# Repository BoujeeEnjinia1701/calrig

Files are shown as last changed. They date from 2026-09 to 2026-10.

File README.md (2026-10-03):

# CalRig

     

**Area:** Open Engineering · **TRL:** 3 of 9 (analytical proof of concept) · **Value-engineering target:** $412 USD (a hypothetical control target, not a limit) · **Difficulty:** 3 of 5

A calibration rig for low-cost sensors: a sealed chamber with controlled temperature, humidity and particle levels plus reference instruments, so every lab sensor can be checked against a known value before and after deployment.

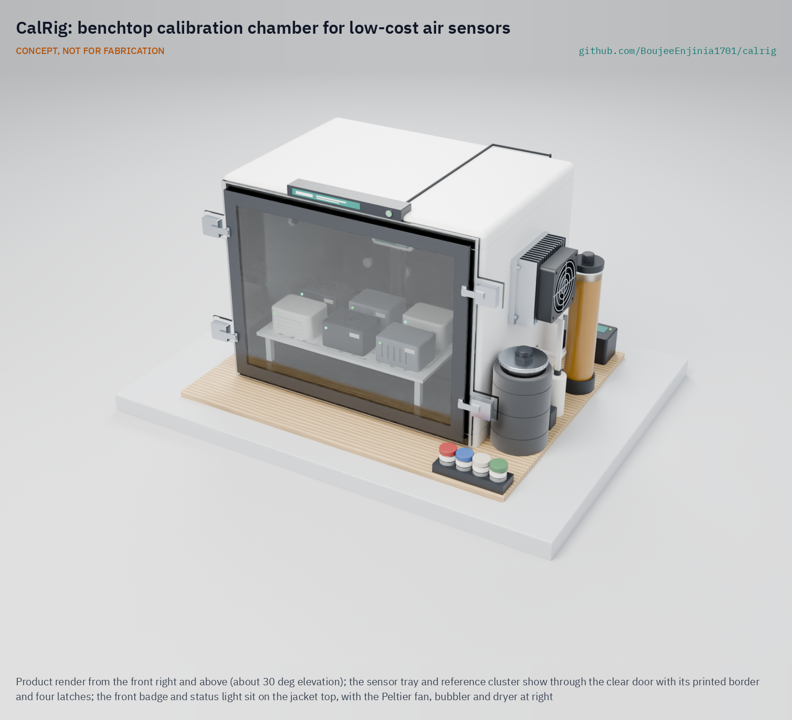
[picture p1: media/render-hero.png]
CalRig: benchtop calibration chamber for low-cost air sensors, product render


[Exploded render](media/render-exploded.png) · [Detail render](media/render-detail.png) · [Interactive 3D model](media/viewer.html) · [Concept blueprint (PDF)](media/concept-blueprint.pdf) · [General arrangement CLR-DWG-001 (PDF)](cad/drawings/CLR-DWG-001.pdf) · [Calculations CLR-CAL-001](docs/04-calcs/01-sizing.md) · [Prototype build plan](docs/05-build-plan.md) · [Review note](docs/REVIEW.md)

## Concept rationale

Calibration is what turns a cheap sensor into a measurement. Most of the error in a low-cost particle, humidity or CO2 sensor comes from temperature, humidity and drift, and those can be set and checked in a small sealed box. CalRig does the chamber half of the recognized method (known conditions, reference instruments, a dated record) and carries a field-collocated reference sensor back to the bench for the particle half, so one shared rig raises the credibility of every sensing project in the lab.

It is open and garage-buildable because the people who most need calibration, community networks and labs in places without regulatory monitors, cannot buy a commercial environmental chamber. Sheet acrylic, a Peltier module, two aquarium-class pumps, silica gel, laboratory salts for humidity fixed points and a microcontroller are available almost everywhere, and an open method lets others check the results.

## Burning platform

Air pollution is a very large health burden, and much of the world measures it with low-cost sensors or not at all. In 2019, 99 % of the world's population lived where WHO air quality guideline levels were not met, and ambient air pollution caused an estimated 4.2 million premature deaths, about 89 % of them in low- and middle-income countries ([WHO fact sheet](https://www.who.int/news-room/fact-sheets/detail/ambient-(outdoor)-air-quality-and-health)). In 2020 OpenAQ found evidence that only 49 % of national governments produced any air quality data ([OpenAQ, 2020](https://documents.openaq.org/reports/Open+Air+Quality+Data+Global+State+of+Play+2020.pdf)).

Low-cost sensors fill that gap only if they are corrected. Raw PurpleAir particle sensors overestimated PM2.5 by about 40 % across most of the United States until a humidity-aware correction cut the error from 8 to 3 µg/m³ ([Barkjohn et al., 2021](https://amt.copernicus.org/articles/14/4617/2021/)), and the UK Air Quality Expert Group warns that without ongoing calibration their useful life "will always be limited" ([DEFRA AQEG](https://uk-air.defra.gov.uk/research/aqeg/pollution-sensors/how-could-I-use.php)).

## Where it could be used

### By industry

| Industry | Use |
| --- | --- |
| Municipal air quality programs | Screen and recheck community PM2.5 sensors before and after each season |
| Universities and schools | Teaching lab for measurement uncertainty; local characterization of sensors for research networks |
| Building services and HVAC | Check CO2 and humidity sensors that drive ventilation control |
| Occupational health | Check the humidity response of wearable particle monitors before field use |
| Agriculture and cold chain | Check temperature and humidity loggers used in grain stores and cold rooms |
| Open hardware and citizen science | Publish a calibration record with every open sensor design |

### By country or region

| Country or region | Why it matters there |
| --- | --- |
| United States | The EPA publishes PM2.5 sensor performance targets and enhanced chamber test conditions ([EPA](https://www.epa.gov/air-sensor-toolbox/frequently-asked-questions-reports-air-sensor-performance-testing-protocols)); CalRig lets community groups report against them without a commercial chamber |
| United Kingdom and European Union | DEFRA's expert group calls for ongoing calibration of sensors ([DEFRA AQEG](https://uk-air.defra.gov.uk/research/aqeg/pollution-sensors/how-could-I-use.php)), and CEN/TS 17660-1 tests sensor systems across temperature and humidity ([CEN/TS 17660-1:2021](https://standards.iteh.ai/catalog/standards/cen/5bdb236e-95a3-4b5b-ba7f-62ab08cd21f8/cen-ts-17660-1-2021)) |
| Uganda and Kenya | Listed by OpenAQ in 2020 among populous countries with no national government air quality monitoring program ([OpenAQ, 2020](https://documents.openaq.org/reports/Open+Air+Quality+Data+Global+State+of+Play+2020.pdf)); local groups already calibrate low-cost sensor networks ([Uganda study](https://www.sciencedirect.com/science/article/pii/S1309104225001825)) |
| Nigeria and West Africa | Nigeria, with about 206 million people, was also on OpenAQ's 2020 list of countries without a national monitoring program ([OpenAQ, 2020](https://documents.openaq.org/reports/Open+Air+Quality+Data+Global+State+of+Play+2020.pdf)); low-cost networks there need local checks in heat and high humidity |
| South and Southeast Asia | WHO reports the greatest burden of ambient air pollution deaths in its South-East Asia and Western Pacific regions ([WHO](https://www.who.int/news-room/fact-sheets/detail/ambient-(outdoor)-air-quality-and-health)); dense sensor networks in humid climates depend on humidity correction |

## What sparked the idea

The idea traces back to the 2020 wildfire season in the western United States. From August to December 2020, the US EPA and the US Forest Service ran the AirNow Sensor Data Pilot, which put readings from a commercial network of PurpleAir sensors on the public Fire and Smoke Map. Before they could do that, EPA researchers had to deal with the fact that the sensors consistently overestimated PM2.5, so they developed a correction equation and quality control checks and validated them for smoke ([EPA, 2021](https://www.epa.gov/sciencematters/research-supports-air-sensor-data-pilot-conducted-2020-wildfire-season)). The lesson is that thousands of low-cost sensors became useful to the public only once someone characterized them against reference instruments in smoke and humid air. CalRig applies the same step at bench scale, so that a small network can check its sensors in known smoke and humidity before its data are published.

## Problem

Low-cost sensors drift and disagree, and without calibration their data is not trusted by cities, regulators or researchers. Full problem statement: [docs/01-problem.md](docs/01-problem.md).

## Concept

A bench-top, 36 L insulated acrylic chamber sets known temperature (10 to 40 °C in rooms up to 25 °C), humidity (20 to 85 % RH) and particle levels (clean air, then a controlled smoke decay from about 300 µg/m³) around up to six sensors. Reference sensors, checked against salt humidity fixed points, an ice point and a 30-day field collocation for the particle reference, give the known values. Larger sensor heads take two or four of the six bays. A controller steps through set points and a laptop script writes a calibration record for each sensor, reported against the US EPA PM2.5 sensor targets.

Calculated performance (TRL 3, [CLR-CAL-001](docs/04-calcs/01-sizing.md)): a four-point sweep plus a particle run takes about 5.5 h unattended; about 90 W peak from an external 12 V supply; 600 x 500 x 383 mm and about 13.9 kg. A larger inner Peltier sink keeps the 85 % RH point at 20 °C dry in rooms up to about 28 °C. Twelve of eighteen requirements are met on paper. Not met: particle traceability until the transfer sensor has been collocated (a first candidate site is named). Value-engineering target: USD 412. Estimated cost of the constructable design: USD 448.50 (USD 36.50 over the target). Each sensor gets a one-page report to the US EPA 2021 targets for PM2.5 sensors. NO2 is calibrated by field collocation, not on CalRig.

Full design precis: [docs/02-concept.md](docs/02-concept.md). Requirements: [docs/03-requirements.md](docs/03-requirements.md).

## Key components

1. Sealed 6 mm acrylic chamber (36 L) with front door and removable insulation jacket
2. 60 W Peltier heat pump with an enlarged inner fin block, and an internal mixing fan
3. Heated bubbler (wet air) and silica gel dryer (dry air), mixed by two pumps
4. HEPA scrubber loop and aerosol injection port for zero air and smoke decay
5. Reference cluster: two Sensirion SHT45, a Sensirion SCD30 (CO2) and a collocated Sensirion SPS30 (PM)
6. Six-bay sensor tray, controller with independent thermal cut-off, certified external 12 V supply
7. Saturated salt fixed-point jars for checking the humidity references

The working bill of materials is in [bom/bom.csv](bom/bom.csv).

## Building the prototype

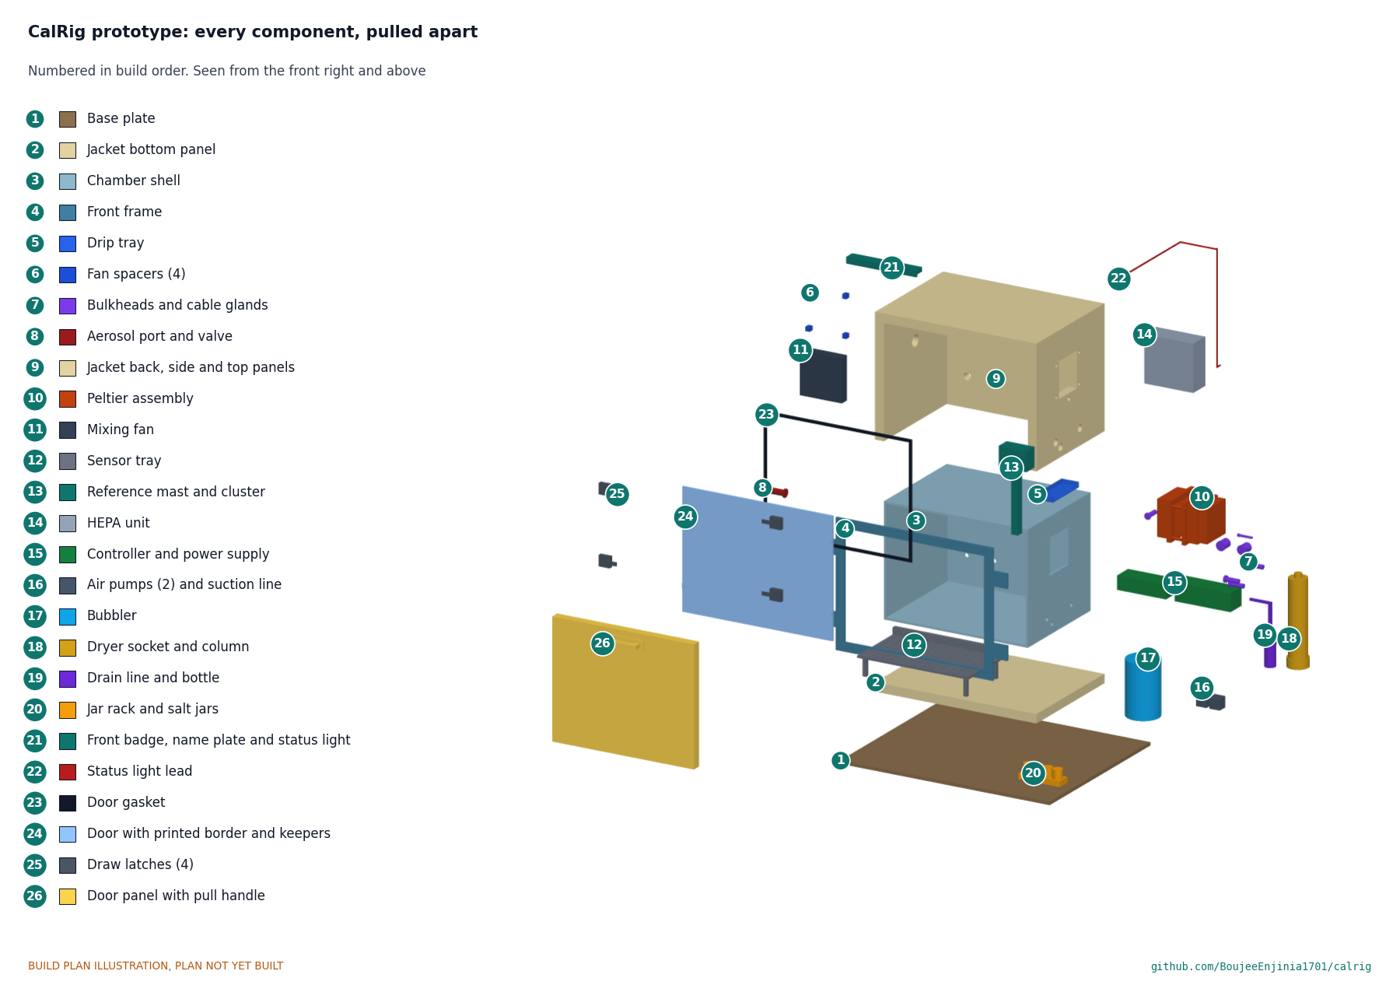
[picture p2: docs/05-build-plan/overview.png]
CalRig prototype: every component pulled apart and numbered in build order


The [prototype build plan](docs/05-build-plan.md) (CLR-BLD-001) shows, in pictures, how to make each of the 26 components and put them together in fourteen steps; nothing has been built yet. The made parts are a laser-cut acrylic chamber with a welded front frame, drip tray and fan spacers, a perforated sensor tray, a clear door, five foam jacket panels and a foam door panel, a sealed plywood base, three printed holders, a front badge with the name plate and a status light, and a pull handle for the door panel; everything else is bought and fitted. Writing the plan made the design buildable: the door now seals on a welded frame with four latches, the heat pump clamps the wall, the air loops, HEPA unit and leads pass through bulkhead fittings and glands, and a drip tray drains to a bottle (CLR-DDR-003, accepted by Amish on 2026-10-02). Every picture is drawn from the model, and the model checks that each part touches what it should and clears what it should not.

## Safety

> **Safety:** No mains wiring inside the rig; use only a certified external 12 V supply. The Peltier hot side reaches 60 to 70 °C and is guarded, with an independent thermal cut-off. Test smoke contains fine particles and some carbon monoxide: light it outside the chamber in a ventilated room and clear the chamber through the HEPA loop before opening. Soda lime is corrosive and lithium chloride is harmful if swallowed; wear gloves and eye protection. No toxic calibration gases are used.

## Repository layout

| Folder | Contents |
| --- | --- |
| `docs/` | Problem, concept, requirements, calculations and design decisions |
| `cad/src/` | build123d Python source, the source of truth for all geometry |
| `cad/step/`, `cad/stl/` | Exported models for FreeCAD, other CAD tools and printing |
| `cad/drawings/` | 2D sketches and dimensioned drawings |
| `bom/` | Bill of materials |
| `electronics/` | KiCad schematics and PCB layouts |
| `firmware/` | Microcontroller code |
| `media/` | Renders, perspectives and photos |
| `build-log/` | Dated prototyping notes |

## Documentation

Controlled documents follow the portfolio [documentation standard](.kit/STANDARDS.md). Each carries a document ID (CLR-PRC-001 for the precis), a version and a revision history. Branded PDFs are built with `python .kit/render.py` and attached to GitHub Releases when a document is tagged, for example `CLR-PRC-001/v1.0`.

## Credits

Designed by Amish Chadha. See [CONTRIBUTORS.md](CONTRIBUTORS.md) for roles. To cite this design, use [CITATION.cff](CITATION.cff) (GitHub shows it as "Cite this repository").

AI assistance (Claude) was used to accelerate concept renders, prototype documentation and first-pass sizing calculations. Design direction and all decisions are Amish Chadha's, recorded in this repository's decision records (`docs/decisions/`).

## Licenses

- **Hardware** (CAD, drawings, BOM, electronics): [CERN-OHL-S v2](LICENSE)
- **Software** (firmware, scripts, notebooks): [MIT](LICENSE-SOFTWARE)

A project of the [Design Molecule](https://designmolecule.com) lab.

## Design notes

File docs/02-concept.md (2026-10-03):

---
doc_id: CLR-PRC-001
title: CalRig design precis
project: CalRig
doc_type: Design precis
version: "0.9"
status: Draft
date: '2026-10-02'
author: Amish Chadha
license: CERN-OHL-S-2.0
revisions:
- version: "0.1"
  date: '2026-09-25'
  author: Amish Chadha
  change: Initial scaffold
- version: "0.3"
  date: '2026-09-25'
  author: Amish Chadha
  change: Populate to TRL 2 (how it works, components, first-order numbers, safety, open questions)
- version: "0.3"
  date: '2026-09-25'
  author: Amish Chadha
  change: TRL 2 review items adopted for TRL 3 work (CLR-DDR-001); numbers replaced by CLR-CAL-001 results; full jacket, 120 mm fan, sleeved bubbler with trace-heated line, 600 x 500 mm base
- version: "0.4"
  date: '2026-09-25'
  author: Amish Chadha
  change: Recommendations accepted by Amish (DDR-002). Larger inner Peltier sink, budget $400, mass limit 14 kg; numbers from CLR-CAL-001 v0.2
- version: "0.5"
  date: '2026-09-26'
  author: Amish Chadha
  change: Budget approved by Amish; $412 budget covers the priced BOM
- version: "0.6"
  date: '2026-10-01'
  author: Amish Chadha
  change: "Constructable design (CLR-DDR-003): front frame, four latches, back-wall glands and bulkheads, drain, 9 mm base; numbers from CLR-CAL-001 v0.4"
- version: "0.7"
  date: '2026-10-01'
  author: Amish Chadha
  change: Budget treated as a value-engineering target; cost wording only, no number changed
- version: "0.8"
  date: '2026-10-02'
  author: Amish Chadha
  change: 'Decisions of 2026-10-02: collocation site first candidate, report format, large heads in two or four bays'
- version: "0.9"
  date: '2026-10-02'
  author: Amish Chadha
  change: 'Approved follow-ups carried out: front badge with name plate and status light, printed door border and pull handle in the design (component 20); per-sensor report template (R14); large heads checked in the model; numbers from CLR-CAL-001 v0.7 (13.9 kg, 383 mm, $448.50)'
---

# CalRig design precis

## Summary

CalRig is a 36 L insulated acrylic chamber on a bench-top base. A Peltier heat pump sets the temperature, a heated bubbler and a silica gel dryer set the humidity, a HEPA loop gives clean air and a controlled smoke decay for particle tests, and a reference cluster (two Sensirion SHT45 temperature and humidity sensors, a Sensirion SCD30 CO2 sensor and a collocated Sensirion SPS30 particle sensor) sits among six sensors under test. A small controller steps through set points, logs everything and shows its state on a status light on the front badge; a laptop script fits a correction for each sensor and writes a dated report to the US EPA 2021 targets (see Per-sensor calibration report). The calculations in CLR-CAL-001 v0.7 show that it meets twelve of the eighteen requirements in CLR-REQ-001. Making the design buildable (CLR-DDR-003, accepted by Amish on 2026-10-02) added a front frame, bulkhead fittings, cable glands, a drain and printed holders, and the details adopted on 2026-10-02 added the front badge, a printed door border and a pull handle. Value-engineering target: USD 412. Estimated cost of the constructable design: USD 448.50 (USD 36.50 over the target; see the value engineering section of CLR-DEC-001). How to build the prototype is in the build plan, CLR-BLD-001. Its particle reference depends on a collocation site; the first candidate is named in CLR-DEC-001.

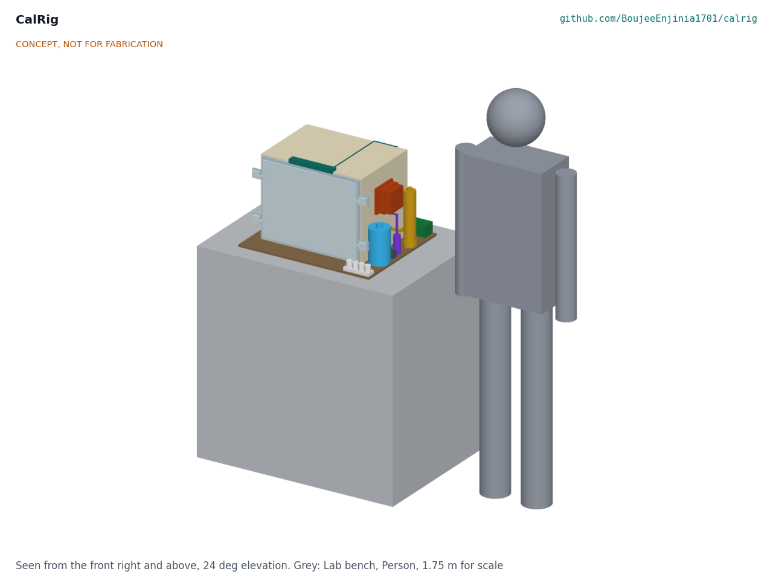
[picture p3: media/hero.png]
Figure 1. CalRig massing model on a lab bench with a 1.75 m person for scale.


Figure 1. CalRig massing model on a lab bench, with a 1.75 m person for scale. Concept, not for fabrication.

## How it works

1. **Load.** Up to six sensor heads sit in the bays of a tray inside the chamber. Their leads pass through two sealed glands in the back wall to a USB and I2C hub on the controller. The door is closed and latched.
2. **Check the references.** Before a campaign (monthly is proposed), the two SHT45 references are checked at four saturated salt fixed points (11, 33, 75 and 84 % RH at 25 °C; [Greenspan, 1977](https://nvlpubs.nist.gov/nistpubs/jres/81A/jresv81An1p89_A1b.pdf)) and in an ice bath at 0 °C. The SPS30 transfer sensor is collocated at a regulatory or research monitor for 30 days or more, and replaced in the chamber only if it meets the US EPA PM2.5 targets there.
3. **Temperature and humidity sweep.** The controller steps through set points, by default 20 °C and 40 °C at 40 % and 85 % RH, matching the EPA enhanced test conditions ([EPA FAQ](https://www.epa.gov/air-sensor-toolbox/frequently-asked-questions-reports-air-sensor-performance-testing-protocols)). The sweep runs from cold to hot, because cooling is the slow direction. The Peltier assembly heats or cools. Two small pumps draw air from the chamber and return it through the bubbler (wet) and the dryer (dry) at a ratio set by PWM, with about 3 L/min in total. The internal 120 mm fan mixes the chamber. Each point settles in about 22 to 31 min, then allows 15 min for the heads to equilibrate, and is held for 30 min (CLR-CAL-001, section I).
4. **Particle run.** With the HEPA loop at full speed (about 20 L/min) the chamber is cleaned to below 2 µg/m³ in about 5 min. A syringe draws a puff of smoke from an incense stick smoldering in a cup outside the chamber and injects it through the aerosol port. The HEPA loop then runs slowly (5 L/min) and the concentration decays from about 300 to 5 µg/m³ in about 28 min, giving a continuous comparison curve. The run can be repeated at a second humidity to fit the humidity term.
5. **CO2 check (optional).** Soda lime in the dryer path gives a near-zero point. One liter of exhaled breath from a bag raises the chamber by about 1,100 ppm for a span point.
6. **Fit and record.** The laptop script compares each sensor with the references, fits a slope, offset and humidity term, computes the EPA metrics (R², slope, intercept, RMSE, sensor-to-sensor precision) and writes a CSV and a one-page report per sensor serial number, laid out as in the per-sensor calibration report below. The status light on the front badge shows whether a run is in progress, settled or finished.

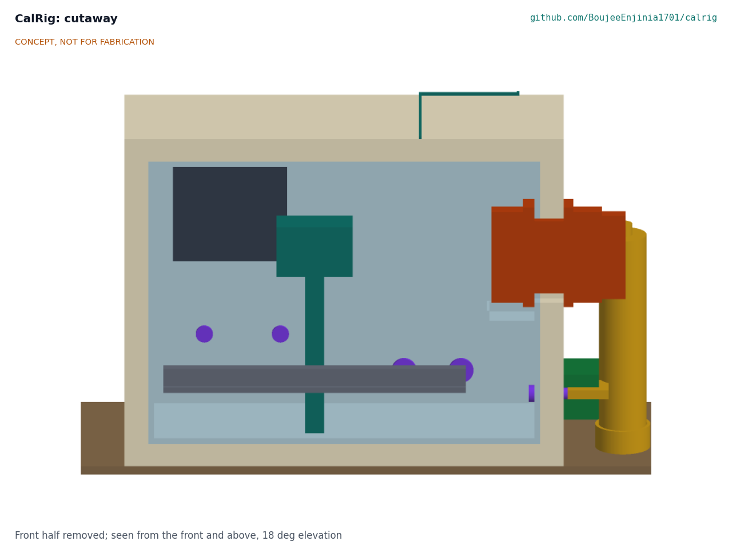
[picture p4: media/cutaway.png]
Figure 2. Cutaway: sensor tray, reference cluster, mixing fan and Peltier assembly.


Figure 2. Cutaway looking from the door side: sensor tray with six example sensors, reference cluster on its mast, mixing fan and the Peltier assembly through the right-hand wall.

## Main components

Table 1. Main components, numbered to match the BOM and the exploded view (Figure 3).

| No. | Component | Role | Key choice |
| --- | --- | --- | --- |
| 1 | Chamber shell | 36 L sealed volume (400 x 300 x 300 mm inside) | 6 mm cast acrylic, solvent-welded; small enough to condition fast, large enough for six heads |
| 2 | Front door | Access and viewing | 430 x 330 mm clear acrylic door with a 22 mm printed black border, on a front frame welded to the shell, silicone gasket, four draw latches; no gland in the door |
| 3 | Insulation jacket | Cuts the chamber conductance to about 0.82 W/K | 25 mm XPS on every face except the door, plus a removable door panel with a printed pull handle for hot, humid and cold points |
| 4 | Base plate | Carries the chamber and conditioners | 9 mm sealed birch plywood, 600 x 500 mm, six rubber feet |
| 5 | Peltier heat pump | Heats and cools the chamber | 60 W air-to-air thermoelectric assembly; the stock inner sink is replaced by a larger fin block (about 45 x 120 x 110 mm, about 0.20 K/W with its fan) so it stays above the dew point at 20 °C and 85 % RH (CLR-DDR-002) |
| 6 | Internal mixing fan | Uniform air across the bays | 120 mm, 12 V, speed-controlled (80 mm was too small for R4) |
| 7 | Sensor tray | Holds six sensor heads, cable rail | Perforated sheet so air moves around the heads |
| 8 | Reference cluster | The known values | 2 x SHT45 (±0.1 °C, ±1.0 % RH typical, [Sensirion](https://sensirion.com/products/catalog/SHT45)), SCD30 (±(30 ppm + 3 %), [Sensirion](https://sensirion.com/products/catalog/SCD30)), SPS30 collocated transfer sensor (±10 % precision, [Sensirion](https://sensirion.com/products/catalog/SPS30)) |
| 9 | Humidifier bubbler | Wet air | 0.3 L of distilled water in a foam-sleeved jar with a 10 W heater pad, held about 3 K above chamber air; trace-heated outlet line so the wet air does not condense on the way; no ultrasonic mist, which would add particles |
| 10 | Dryer column | Dry air | Indicating silica gel, about 500 g, regenerated in an oven |
| 11 | HEPA scrubber loop | Zero air and controlled smoke decay | H13 class filter cartridge with a variable-speed fan, joined to the chamber by two bulkheads in the back wall |
| 12 | Aerosol injection port | Smoke entry | Luer port with a ball valve; the smoke source stays outside |
| 13 | Controller and power board | Control, logging and protection | ESP32 class board, Peltier H-bridge, pump and fan MOSFETs, a status light output, microSD, independent thermal cut-off |
| 14 | Power supply | 12 V, 10 A | Certified external brick; no mains wiring in the rig |
| 15 | Salt fixed-point jars | Humidity reference checks | LiCl, MgCl2, NaCl and KCl slurries in sealed jars |
| 19 | Bulkhead fittings, glands and drain | Air, water and leads through the sealed walls | Five 12 mm bulkheads, a 6 mm drain, two M20 cable glands in the back wall, 250 mL drain bottle |
| 20 | Front badge, status light and name plate | Shows run state without opening the rig | Printed badge on the jacket's top panel with a 12 V panel light and the name plate; lead to the controller |

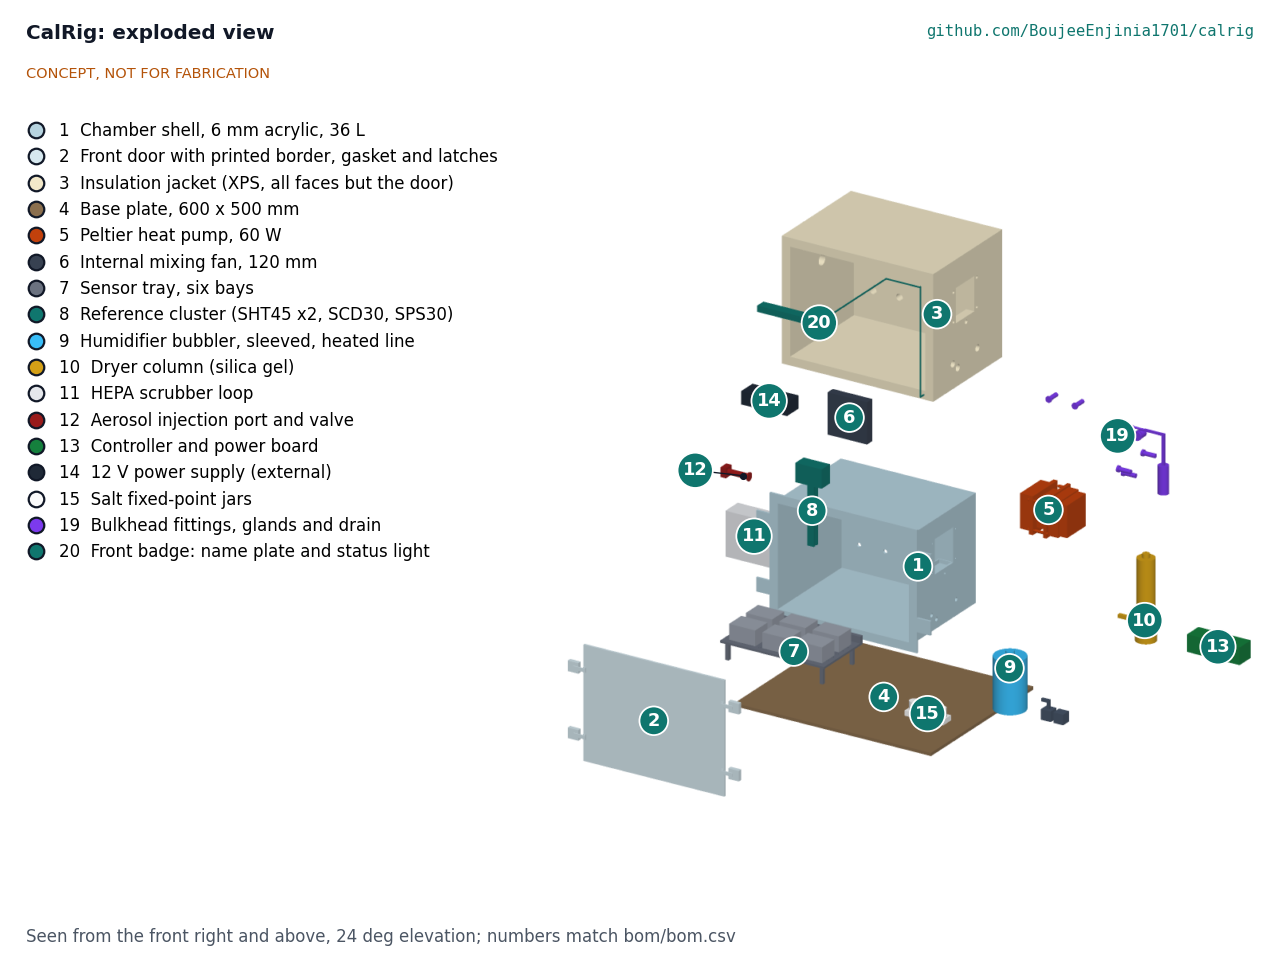
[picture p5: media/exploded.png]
Figure 3. Exploded view with BOM numbers.


Figure 3. Exploded view. Callout numbers match Table 1 and `bom/bom.csv`.

## Key numbers

All values come from CLR-CAL-001 v0.7, which gives the assumptions and the script tags. They are calculations, not measurements.

Table 2. Chamber and process figures.

| Quantity | Value | Basis |
| --- | --- | --- |
| Internal volume | 36.0 L | 400 x 300 x 300 mm |
| Chamber conductance | 0.82 W/K with door panel; 1.17 W/K without | Full jacket (U 1.01 W/(m²·K)), 20 % for thermal bridges, conditioning loop 0.06 W/K |
| Internal heat gains | 6.7 W | Fans 3.9 W, six heads 2.4 W, references 0.4 W |
| Water to go from 20 to 85 % RH at 40 °C | 1.8 g | 1.19 g in the air, about 0.59 g into the acrylic surface |
| Settling per set point | 22 to 31 min, plus 15 min for the heads | Loop time constant 12 min; full-drive thermal ramps |
| Four-point sweep plus particle run | about 5.5 h | Cold to hot, 30 min holds |
| Decay 300 to 5 µg/m³ | about 28 min | HEPA 5 L/min, deposition 0.2 per hour |
| CO2 span from 1 L of breath | about +1,100 ppm | Exhaled air about 4 % CO2 |
| Peak electrical power | about 90 W, 7.5 A at 12 V | Peltier 59 W, heaters 13 W, pumps, fans, controller, sensors |
| Overall size and mass | 600 x 500 x 383 mm; about 13.9 kg | Parametric model `cad/src/model.py` (the front badge sets the height) |
| Capacity | Six heads up to 90 x 70 x 50 mm; or larger heads up to 192 x 70 mm on two bays or 192 x 152 mm on four, up to 234 mm tall | Model checks, CLR-CAL-001 [A2, A4] |

Table 3. Temperature range with one 12706-class module at 12 V (CLR-CAL-001, section B).

| Room | Lowest chamber temperature | Heating to 40 °C |
| --- | --- | --- |
| 15 °C | -2.0 °C | 13.9 W needed, about 80 W available |
| 22 °C | 4.1 °C | 8.1 W needed, about 86 W available |
| 25 °C | 6.7 °C | Met |
| 30 °C | 11.1 °C | Met |

The revised R1 (10 °C in rooms of 15 to 25 °C) is met, with a 3.3 K margin at 25 °C. Cooling to 10 °C is slow, about 2.5 h in a 25 °C room, so cold points are a separate run.

**Condensation at the hot, humid point.** At 40 °C and 85 % RH the dew point is 37.0 °C. The inner face of the clear door in a 22 °C room runs at about 33 °C and condenses; with the door panel fitted it runs at about 38.2 °C, a 1.2 K margin (0.5 K in a 15 °C room). The door panel is therefore required for that point, and the wet air line is trace-heated.

**Condensation on the Peltier sink.** Holding 20 °C in the 22 °C reference room still needs about 8 W of cooling, mostly to remove the internal gains. With the stock inner sink (0.45 K/W) the sink ran about 1.2 K below the 17.4 °C dew point of air at 85 % RH and would condense about 8 g/h against about 0.7 g/h from the bubbler. The larger inner fin block (about 0.20 K/W, CLR-DDR-002) runs at about 18.3 °C, 0.9 K above the dew point, so the point holds in rooms up to about 28 °C (R2 met). A drip tray and drain stay in the design for cold points.

**Particle reference.** The chamber cannot create a traceable mass reference. It carries one from the field: a transfer SPS30 that has been collocated with a regulatory or research monitor. Chamber results then describe how each sensor compares with that transfer sensor in combustion smoke at known humidity. Reports must state the aerosol type, because optical sensors respond differently to dust, salt and smoke.

## Key design choices

These were decided by Amish on 2026-09-25 (go with recommendation; CLR-DDR-001 and CLR-DDR-002).

- **Transfer references instead of certified instruments.** Certified reference instruments cost thousands of dollars. CalRig uses good digital sensors, checked against physical fixed points (salts, ice) and field collocation. This keeps the rig near its value-engineering target and makes the uncertainty chain explicit.
- **Heated bubbler, not an ultrasonic mister.** Ultrasonic misters make mineral particles that would corrupt particle tests.
- **Smoke decay, not a nebulizer.** A decay curve covers the whole range in one run with no dilution hardware. Every report states the aerosol type (CLR-DDR-001 A4).
- **Accept the cooling limit.** One Peltier module; 10 °C only in rooms at 25 °C or below, and the lowest point stated in each record for warmer rooms (CLR-DDR-001 A3).
- **Insulated door panel** for hot, humid and cold points (CLR-DDR-001 A6).
- **Larger inner Peltier sink** (about 0.20 K/W) so the 20 °C, 85 % RH point holds in normal rooms (CLR-DDR-002).
- **Mass limit of 14 kg.** CalRig is a bench rig, so the 12 kg limit was relaxed rather than thinning the acrylic (CLR-DDR-002).
- **Certified temperature probe if the cost target allows.** It does not yet (the BOM is already above the $412 value-engineering target), so R5 stays at risk (CLR-DDR-002).
- **External 12 V supply.** Keeps mains voltage out of a box that holds water.
- **Temperature and humidity first, CO2 optional, no toxic gases.** NO2 sensors, including AirStreet's, are calibrated by field collocation only (CLR-DDR-001 A5).

## Links to other projects

- **AirStreet** describes itself as "calibrated on CalRig" for PM2.5 and NO2. CalRig covers PM2.5 and the temperature and humidity terms; AirStreet's README already states that NO2 is calibrated by field collocation.
- **HeatMap Node** (heat and humidity), **DustBadge** (dust) and **FieldNode** sensor heads are intended users. Larger heads take more than one bay: a head up to 192 x 70 mm in plan takes two bays side by side, and one up to 192 x 152 mm, such as HeatMap Node's 150 mm globe, a 2 x 2 block of four bays (R10). DustBadge measures respirable dust, so a smoke-based chamber result will not transfer directly to mineral dust.

## Per-sensor calibration report (R14)

Each sensor head gets a one-page report, keyed by its serial number, written from the run's CSV. The report follows the US EPA 2021 performance targets and testing protocol for PM2.5 air sensors (EPA/600/R-20/280, [EPA](https://www.epa.gov/air-sensor-toolbox/air-sensor-performance-targets-and-testing-protocols)), and states its uncertainty chain back to the salt and ice fixed points and the collocation record. It is a research and calibration record for a low-cost sensor, not a certificate of conformity: chamber results compare each sensor with a transfer reference in incense smoke, and the EPA targets are set for 24 h field averages against a regulatory monitor, so the chamber comparison is indicative and says so.

Table 4. Per-sensor report template.

| Section | Contents |
| --- | --- |
| 1. Identification | Sensor make, model, serial number and firmware; CalRig serial and software version; run date, operator; bay position, or the two- or four-bay position for a large head |
| 2. Run conditions | Set points as run (20 °C and 40 °C at 40 % and 85 % RH by default), room temperature, the lowest set point reachable in that room (R1), averaging interval, hold length, number of points; aerosol type (incense smoke) and decay range |
| 3. Reference status | SHT45 serials, date of the last ice-point and salt fixed-point checks and their offsets; transfer SPS30 serial, collocation site, dates (30 days or more), and its collocation results (R², slope, intercept, RMSE) against the regulatory monitor; SCD30 if used, with its datasheet tolerance (no traceable CO2 reference) |
| 4. Fitted correction | Slope, offset and humidity term for PM2.5, with their standard errors; offset and slope for temperature and RH where the sensor reports them |
| 5. EPA metrics, raw and corrected | Slope (target 1.0 ± 0.35), intercept (-5 to +5 µg/m³), R² (0.70 or more), RMSE (7 µg/m³ or less) or NRMSE (30 % or less), and, where three or more of the same model ran together, precision as standard deviation (5 µg/m³ or less) or coefficient of variation (30 % or less); each shown against its target |
| 6. Enhanced conditions | Response at each temperature and humidity set point; humidity influence; drift since the last report for this serial, if there is one |
| 7. Uncertainty chain | Temperature: ice point, SHT45 after offset, drift, gradient to the bay, expanded U (k = 2) from CLR-CAL-001 [F1]. Humidity: salt fixed points (Greenspan, 1977), jar gradient, hysteresis, interpolation and temperature terms, expanded U (k = 2) [F3]. Particles: regulatory monitor at the collocation site, transfer SPS30 collocation results, chamber bay-to-reference gradient, fit residuals; expanded U (k = 2) of the corrected PM2.5 at 35 µg/m³ |
| 8. Limits of use | Aerosol type, ranges covered, the date after which the reference checks lapse, and the statement that the results describe this sensor against the transfer reference in smoke at known humidity |

Values and their units come from the run's CSV and from CLR-CAL-001; the report writer is part of the control and fitting software (BOM line 18), written at TRL 4.

## Safety

> **Safety:** The Peltier hot-side heat sink can reach 60 to 70 °C; keep it guarded and away from the acrylic. An independent thermal cut-off opens the heater circuit at 50 °C chamber air or 70 °C hot side. The 12 V bus carries up to about 7.5 A: fuse it at 10 A at the supply and use rated wire. The bubbler heater pad and the line trace each have a thermistor and are switched off by the same cut-off. Use only a certified external supply; never wire mains into the rig, which contains water.

> **Safety:** Test smoke contains fine particles and combustion gases, including carbon monoxide in small amounts. Light the incense in a cup outside the chamber, in a ventilated room, and run the HEPA loop until the reference reads below 5 µg/m³ before opening the door. No toxic calibration gases are used in this version.

> **Safety:** Soda lime is corrosive and lithium chloride is harmful if swallowed. Wear gloves and eye protection when filling cartridges and salt jars, label them, and keep them away from children. Cast acrylic is combustible: keep heaters and hot surfaces off the shell. Keep electronics below and outside the chamber so condensation cannot reach them. Fans have guards. Exhaled air for CO2 checks goes through a single-user bag and filter.

## Open questions

- [x] Value-engineering target: USD 412 in parts, a hypothetical control target set by Amish on 2026-09-26 (CLR-DDR-002). Estimated cost of the constructable design: USD 448.50 (USD 36.50 over the target); savings worth trying are in the value engineering section of CLR-DEC-001.
- [x] Particle reference: a state or local regulatory monitoring site with a federal equivalent PM2.5 monitor (decided 2026-10-02, CLR-DEC-001). First candidate to approach: a Texas Commission on Environmental Quality site in Dallas-Fort Worth; fallback: South Coast AQMD's AQ-SPEC program. How often the transfer SPS30 returns there is still to be set.
- [ ] Inner fin block: confirm a part that reaches about 0.20 K/W with the inner fan.
- [x] Report format: based on the US EPA 2021 performance targets and testing protocol for PM2.5 air sensors, with a stated uncertainty chain from the salt and ice fixed points and the collocation record (decided 2026-10-02, CLR-DEC-001); template in Table 4.

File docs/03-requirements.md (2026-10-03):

---
doc_id: CLR-REQ-001
title: CalRig requirements
project: CalRig
doc_type: Requirements
version: "0.9"
status: Draft
date: '2026-10-02'
author: Amish Chadha
license: CERN-OHL-S-2.0
revisions:
- version: "0.1"
  date: '2026-09-25'
  author: Amish Chadha
  change: Initial scaffold
- version: "0.3"
  date: '2026-09-25'
  author: Amish Chadha
  change: First measurable requirements for TRL 2, with first-order status
- version: "0.3"
  date: '2026-09-25'
  author: Amish Chadha
  change: R1 redefined per CLR-DDR-001 A3; status column replaced by the CLR-CAL-001 results; budget note per A1
- version: "0.4"
  date: '2026-09-25'
  author: Amish Chadha
  change: Recommendations accepted by Amish (DDR-002). R12 target $400, R13 mass relaxed to 14 kg, statuses from CLR-CAL-001 v0.2
- version: "0.5"
  date: '2026-09-26'
  author: Amish Chadha
  change: Budget approved by Amish; R12 target $412, status Not met to Met
- version: "0.6"
  date: '2026-10-01'
  author: Amish Chadha
  change: Statuses from CLR-CAL-001 v0.4 for the constructable design (CLR-DDR-003); R12 Met to Not met ($439), budget rise proposed; R13 figures updated
- version: "0.7"
  date: '2026-10-01'
  author: Amish Chadha
  change: Budget treated as a value-engineering target; cost wording only, no number changed
- version: "0.8"
  date: '2026-10-02'
  author: Amish Chadha
  change: 'Decisions of 2026-10-02 (CLR-DEC-001): R8 first candidate collocation site named; R10 large item case added; R14 report based on the US EPA 2021 targets and protocol with an uncertainty chain. No status changed'
- version: "0.9"
  date: '2026-10-02'
  author: Amish Chadha
  change: 'Statuses from CLR-CAL-001 v0.7: R10 met including the large item case (was met for six heads only); R12 over the value-engineering target by USD 36.50 (was USD 27); R13 figures 383 mm and 13.9 kg, still met; R14 report template defined, still not verifiable at TRL 3'
---

# CalRig requirements

These requirements have been checked by calculation in CLR-CAL-001 v0.7. Targets are not yet validated with users. R1 was redefined under CLR-DDR-001 (item A3); R12 and R13 were restated under CLR-DDR-002. All three changes were decided by Amish on 2026-09-25 (go with recommendation). Test conditions follow the enhanced lab conditions in the US EPA sensor testing reports (20 °C and 40 °C; 40 % and 85 % RH) so that CalRig results can be read against a known method ([EPA FAQ](https://www.epa.gov/air-sensor-toolbox/frequently-asked-questions-reports-air-sensor-performance-testing-protocols)).

The **reference room** is an indoor lab at 22 °C and 50 % RH unless a requirement states otherwise.

Table 1. Requirements with targets and status from CLR-CAL-001 (Table 4 there gives the values and script tags).

| ID | Requirement | Target | Verification (TRL 3 or later) | Status (CLR-CAL-001) |
| --- | --- | --- | --- | --- |
| R1 | Chamber temperature range | 10 to 40 °C at the sensor tray in a room at 15 to 25 °C; in rooms from 25 to 30 °C, the lowest reachable set point is stated in each calibration record | Heat balance with a thermoelectric model; later chamber log | Met: 6.7 °C reachable in a 25 °C room; 11.1 °C lowest in a 30 °C room |
| R2 | Chamber humidity range | 20 to 85 % RH at any temperature from 20 to 40 °C | Moisture balance; later chamber log | Met: all corners reached in 26 min or less; with the larger inner sink (DDR-002) 20 °C and 85 % RH holds in rooms up to about 28 °C, with a 0.9 K dew point margin in the reference room |
| R3 | Stability at a set point | ±0.3 °C and ±2 % RH over a 30 min hold | Controller simulation; later log | Met on an idealized model: ±0.02 °C, ±1.0 % RH |
| R4 | Uniformity across the six bays | ±0.3 °C and ±2 % RH between bays | Airflow estimate; later traverse with two references | At risk: ±0.18 °C at the EPA points with the 120 mm fan, ±0.42 °C at 10 °C; ±0.8 % RH |
| R5 | Reference temperature uncertainty | 0.2 °C or better (expanded, k = 2) from 10 to 40 °C | Uncertainty budget; ice-point check | At risk: 0.14 °C with the typical sensor tolerance, 0.24 °C if it is 0.2 °C; no calibration certificate |
| R6 | Reference humidity uncertainty | 2 % RH or better (expanded) from 20 to 85 % RH, checked at four salt fixed points | Uncertainty budget; salt fixed-point checks ([Greenspan, 1977](https://nvlpubs.nist.gov/nistpubs/jres/81A/jresv81An1p89_A1b.pdf)) | At risk: 2.0 % RH, no margin |
| R7 | Particle test range | Zero below 2 µg/m³ PM2.5; controlled decay from 300 to 5 µg/m³ in 45 min or less | Decay calculation; later run | Met: 5 min clean-down; 28 min decay |
| R8 | Particle reference traceability | Transfer PM sensor collocated with a regulatory or research monitor for 30 days or more, and meeting EPA PM2.5 targets there, before use as the chamber reference | Collocation record | **Not met by the rig alone.** First candidate site chosen on 2026-10-02 (CLR-DEC-001): a Texas Commission on Environmental Quality site in Dallas-Fort Worth, still to be approached; no collocation done yet |
| R9 | CO2 check | Zero check below 50 ppm with soda lime; span 400 to 2000 ppm against a reference of ±(30 ppm + 3 %) | Calculation and datasheet ([Sensirion SCD30](https://sensirion.com/products/catalog/SCD30)); later run | Met: 8 ppm floor; about 1,100 ppm added per liter of breath |
| R10 | Capacity | Six sensor heads per run, each up to 90 x 70 x 50 mm, with power and I2C, UART or USB leads through a sealed gland. Large item case (CLR-DEC-001, 2026-10-02): a head up to 192 x 70 mm in plan takes two bays side by side, and a head up to 192 x 152 mm a 2 x 2 block of four bays, within the 244 mm clear height, with fewer heads per run | Model check | Met: six bays, 244 mm clear above the tray; large heads up to 234 mm tall fit in every two-bay and four-bay position (model checks, CLR-CAL-001 [A4]) |
| R11 | Throughput | Four-point temperature and humidity sweep plus one particle decay run in 8 h or less, unattended | Timing estimate; later log | Met: about 5.5 h |
| R12 | Cost | Within the $412 value-engineering target for parts (`budget_usd`, a hypothetical control target; raised from $300 to $400 on 2026-09-25 and to $412 on 2026-09-26 under CLR-DDR-002) | Priced BOM (`bom/bom.csv`) | **Over the value-engineering target by USD 36.50:** USD 448.50 estimated after the parts added to make the design buildable (CLR-DDR-003) and the front badge, door border and pull handle adopted on 2026-10-02 |
| R13 | Size and mass | Fits a 600 x 500 mm bench area, 400 mm high or less; 14 kg or less (relaxed from 12 kg under CLR-DDR-002) | Model; mass estimate | Met: 600 x 500 x 383 mm; about 13.9 kg (0.08 kg margin) |
| R14 | Records | Every run writes CSV (time, set points, references, each sensor) and a per-sensor report based on the US EPA 2021 performance targets and testing protocol for PM2.5 air sensors, with fitted slope, offset and humidity term, EPA metrics, the reference check dates and the uncertainty chain from the salt and ice fixed points and the collocation record (CLR-DEC-001, 2026-10-02) | Software review | Not verifiable at TRL 3: report template defined (CLR-PRC-001, Table 4); software not written |
| R15 | Electrical safety | No mains wiring in the rig; certified external 12 V supply; fused 12 V bus; peak draw 100 W or less | Design review; power budget | Met: about 90 W, 7.5 A peak |
| R16 | Thermal safety | Independent hardware cut-off opens the heater circuit at 50 °C air temperature or 70 °C Peltier hot side | Design review; heat balance | Met: outer sink 50 °C at most in normal use |
| R17 | Aerosol and gas safety | No toxic gases; test smoke vented through the HEPA loop before the door opens; smoke source outside the chamber | Design review | Met by design |
| R18 | Garage-buildable | Built with a saw or laser cutter, a drill and a soldering iron; all active parts off the shelf | Design review | Met by design |

## Requirements not met or at risk

- **R8**, particle traceability. The chamber cannot make a mass reference; it transfers one from a collocation site. The first candidate to approach, chosen on 2026-10-02, is a Texas Commission on Environmental Quality site in Dallas-Fort Worth, with South Coast AQMD's AQ-SPEC program as the fallback; R8 stays not met until the transfer sensor has been collocated there.
- **R4**, **R5** and **R6** are at risk (uniformity at cold points, sensor tolerance and humidity budget without margin). A certified temperature probe for R5 is decided if the cost target allows; the estimated cost is already above the $412 value-engineering target, so it does not yet.
- R2 and R13 moved to met in v0.4 (larger inner sink; mass limit relaxed to 14 kg). R12 moved to within the value-engineering target in v0.5: the target was set by Amish on 2026-09-26 at $412, which covered the priced BOM then.
- **R12**, cost, moved in v0.6 to over the value-engineering target by $27: the front frame, bulkhead fittings, cable glands, drain and printed holders that make the design buildable (CLR-DDR-003) brought the estimated cost to $439. In v0.9 the front badge, door border and pull handle adopted on 2026-10-02 add $9.50. Value-engineering target: USD 412. Estimated cost of the constructable design: USD 448.50 (USD 36.50 over the target). The target is a hypothetical control target, not a limit; savings worth trying are in the value engineering section of CLR-DEC-001. R13 stays met at about 13.9 kg with a 9 mm base, with a 0.08 kg margin.
- **R10** moved in v0.9 from met for six heads to met including the large item case, checked in the model.

## Assumptions

- Chamber conductance about 0.82 W/K with the full jacket and door panel fitted, and 6.7 W of internal gains (CLR-CAL-001).
- Settling is limited by the 3 L/min conditioning flow, moisture held on the walls and a 15 min equilibration allowance for the heads.
- Test aerosol is incense smoke (CLR-DDR-001 A4); results for other aerosols (dust, sea salt) will differ and must be stated in each report.

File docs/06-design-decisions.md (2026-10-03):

---
doc_id: CLR-DEC-001
title: CalRig design decisions register
project: CalRig
doc_type: Design decisions register
version: "0.4"
status: Draft
date: '2026-10-02'
author: Amish Chadha
license: CERN-OHL-S-2.0
revisions:
  - version: "0.1"
    date: '2026-10-01'
    author: Amish Chadha
    change: Register opened with the build plan; open items gathered from the review note, the decision records and the build work
  - version: "0.2"
    date: '2026-10-01'
    author: Amish Chadha
    change: Budget treated as a value-engineering target
  - version: "0.3"
    date: '2026-10-02'
    author: Amish Chadha
    change: 'Amish approved the recommendations for all seven open decisions on 2026-10-02 (CLR-DDR-003 accepted); moved to decisions made'
  - version: "0.4"
    date: '2026-10-02'
    author: Amish Chadha
    change: 'Approved follow-ups carried out: value engineering restated (USD 448.50 on 20 lines, USD 36.50 over the target); items 8 and 9 to confirm (status light, door border); open decision 1 (badge placement)'
---

# CalRig design decisions register

Every design decision still to be made, and every decision made, in one place. Each decision is argued in full in its decision record under `docs/decisions/`; this register is the index Amish works from. The build plan (`docs/05-build-plan.md`) describes the design as it stands and does not list open decisions.

## Open decisions

| # | To decide | Options | Recommendation | What it affects in the build | Source |
| --- | --- | --- | --- | --- | --- |
| 1 | Where the name plate and status light sit. The front frame covers the jacket's front edges to 6 mm below the top, so the design places them on a printed badge on the top panel, its lip on the frame's top edge; this raises the overall height from 371 to 383 mm | (a) badge on the top panel, as modelled; (b) badge recessed into a notch in the top panel's front edge, no added height, harder foam cut | (a): simplest to make, and the rig stays 17 mm under the 400 mm limit of R13 | Front badge (section 3.15 and step 12 of the build plan), overall height | REVIEW 2026-10-02, approved follow-ups |

All earlier open decisions were decided on 2026-10-02.

## To confirm when parts are bought

| # | What to confirm | Why it matters | Source |
| --- | --- | --- | --- |
| 1 | The heat pump's sink bases are at least 120 x 110 mm and take four M4 clamp screws at 57 mm either side and 42 mm above and below centre | The bases clamp the wall over the 90 x 100 mm opening; the shell's clamp holes are cut to match | CLR-DDR-003, P3 |
| 2 | An inner fin block and fan that reach about 0.20 K/W | R2 at 20 °C and 85 % RH depends on it | CLR-DDR-002, D7; CLR-PRC-001, open questions |
| 3 | The draw latches fit a 41 x 40 mm tab and reach a keeper 15 mm in from the tab edge | Sets the frame tab size and the keeper position | CLR-DDR-003, P1 |
| 4 | The thread sizes of the bulkhead fittings (12 and 6 mm), cable glands (M20) and aerosol bulkhead (16 mm), and that the multi-hole gland inserts suit the sensor leads | The shell holes are laser cut to these sizes before anything is fitted | CLR-DDR-003, P7 to P11 |
| 5 | The HEPA unit's ports are 12 mm and 80 mm apart at 117 mm above the bench, or can be drilled to that | The back-wall fittings run straight into them | CLR-DDR-003, P8 |
| 6 | The SHT45 tolerance the supplier states (0.1 or 0.2 °C) | R5 is at risk if it is 0.2 °C | CLR-CAL-001, [F1] |
| 7 | The bimetal switches and relay: opening temperatures of 50 and 70 °C and a relay rated 10 A at 12 V direct current | R16 rests on them | CLR-DDR-003, Table 2 |
| 8 | The 12 V panel indicator light is 5 mm with an 8 mm bezel and a built-in resistor, and fits a 5.2 mm hole in an 18 mm badge face | Sets the badge hole and the controller output | CLR-DEC-001, 2026-10-02 (appearance item 3) |
| 9 | The print shop can cut the 22 mm vinyl border with the four keeper notches, in a vinyl that takes the 40 °C, 85 % RH point on the door's outer face | The border must stay flat on the door | CLR-DEC-001, 2026-10-02 (appearance item 4) |

## Value engineering

Value-engineering target: USD 412 (a hypothetical control target, not a limit). Estimated cost of the constructable design: USD 448.50 (USD 36.50 over the target).

Main cost drivers (CLR-CAL-001, K): the reference cluster (line 8, $132), the chamber shell (line 1, $51), the Peltier heat pump (line 5, $40), the parts added for construction ($27, of which new line 19, bulkhead fittings, cable glands and drain, is $14) and the details adopted on 2026-10-02 ($9.50: front badge, status light, name plate and lead, line 20, $5.50; door border $3; pull handle $1). The CO2 path (SCD30 in the reference cluster and soda lime, line 16, $8) is the largest block that is not core to the temperature, humidity and particle functions.

Savings worth trying:

- A core version without CO2 (no SCD30, no soda lime), about USD 381.50; this changes what the rig does and would be proposed, not made (CLR-DDR-003, A1).
- Re-pricing the fittings, glands and drain (line 19) and the front frame, drip tray and spacers ($6) at purchase.
- Looking for savings in the reference cluster and shell; no single line obviously offers $36.50.

## Decisions made

| Date | Decision | Decided by | Record |
| --- | --- | --- | --- |
| 2026-09-25 | TRL 2 review items A1 to A6: budget raised to $400, transfer references checked at salt and ice fixed points, accept the cooling limit (R1 redefined), incense smoke decay, carbon dioxide optional and nitrogen dioxide by field collocation only, insulated door panel | Amish: "i accept all your recommendations, go with them across all repos." | CLR-DDR-001, CLR-DDR-002 |
| 2026-09-25 | Larger inner fin block (about 0.20 K/W); R13 relaxed to 14 kg; certified temperature probe only if the budget allows | Amish, same instruction | CLR-DDR-002, D7 to D9 |
| 2026-09-26 | Budget set to $412 to cover the priced BOM as it then stood | Amish: "i approve all the budget items." | CLR-DDR-002, O2 |
| 2026-10-02 | Design for construction accepted: the changes P1 to P12 and their knock-on changes, including the 9 mm sealed birch plywood base, as made | Amish: "i approve your recommendations for all 555 open decisions." | CLR-DDR-003, Tables 1 and 2 |
| 2026-10-02 | Mass margin of 0.17 kg accepted on paper; the finished rig is weighed at TRL 4, and a 5 mm acrylic top is the first fallback if it weighs over 14 kg | Amish: "i approve your recommendations for all 555 open decisions." | CLR-DDR-003, A2 |
| 2026-10-02 | Base plate: sealed 9 mm birch plywood, as modelled; the renders are to show plywood too, so they match what will be built | Amish: "i approve your recommendations for all 555 open decisions." | CLR-DDR-003, A3; REVIEW 2026-09-26, item 2 |
| 2026-10-02 | Collocation partner for the transfer SPS30: a state or local regulatory monitoring site with a federal equivalent PM2.5 monitor. First candidate to approach: a Texas Commission on Environmental Quality site in Dallas-Fort Worth; fallback: South Coast AQMD's AQ-SPEC program | Amish: "i approve your recommendations for all 555 open decisions." | CLR-DDR-001, O1 |
| 2026-10-02 | Appearance model items: jacket facing (1) in renders only, decided at TRL 4; status light and name plate (3), printed door border (4, with no gland in the door, since P9 put the glands in the back wall) and door panel pull handle (5) adopted in the design; bubbler and dryer details, fan guards, example heads and valve lever (6 to 9) accepted as drawn | Amish: "i approve your recommendations for all 555 open decisions." | REVIEW 2026-09-26, items 1 and 3 to 9 |
| 2026-10-02 | Calibration report based on the US EPA 2021 performance targets and testing protocol for PM2.5 air sensors, with a stated uncertainty chain from the salt and ice fixed points and the collocation record | Amish: "i approve your recommendations for all 555 open decisions." | CLR-PRC-001, open questions |
| 2026-10-02 | R10 gains a large item case: a head up to 192 x 152 mm in plan takes a 2 x 2 block of four bays, and a head up to 192 x 70 mm takes two bays side by side, within the 244 mm clear height | Amish: "i approve your recommendations for all 555 open decisions." | REVIEW 2026-09-25, cross-repo notes |

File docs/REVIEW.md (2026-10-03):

# Review note: CalRig

## Session 2026-09-25: /populate to a strong TRL 2

### What was done

- `docs/01-problem.md` (CLR-PRB-001 v0.2): the problem (humidity bias, temperature dependence and drift in low-cost sensors), users and operating environment, constraints, out of scope, prior work with sources (EPA targets, AQ-SPEC, Greenspan salt fixed points, Uganda calibration work), open questions. There was no co-design checklist to keep.
- `docs/03-requirements.md` (CLR-REQ-001 v0.2): 18 measurable requirements (R1 to R18) with targets, planned verification and a first-order status column; requirements not met listed plainly.
- `docs/02-concept.md` (CLR-PRC-001 v0.2): how it works, components table numbered to the BOM, first-order numbers with assumptions, heat balance at the temperature limits, condensation check, particle reference approach, design choices, links to AirStreet, HeatMap Node, DustBadge and FieldNode, safety section, open questions.
- `cad/src/concept_media.py`: massing model with 15 numbered parts (chamber shell, door, insulation jacket, base plate, Peltier heat pump, mixing fan, sensor tray, reference cluster, bubbler, dryer, HEPA loop, aerosol port, controller, power supply, salt jars), example sensors under test, and a lab bench with a 1.75 m person for scale in the hero only.
- `media/`: `hero.png`, `concept-blueprint.png`, `.pdf` and `.svg`, `model.glb` and `viewer.html`, `exploded.png` with BOM callouts, `cutaway.png`, `flow.png` (calibration run; durations marked as estimates). Temporary `_views` folders removed.
- `bom/bom.csv`: 18 priced lines in the existing column format, lines 1 to 15 matching the exploded view.
- `README.md`: hero image and links line; Concept rationale, Burning platform, Where it could be used (6 industries, 5 regions), What sparked the idea, Problem, Concept, Key components and Safety expanded, headings and order unchanged.
- `docs/pdf/`: branded PDFs of the three controlled documents.
- `project.yaml`: unchanged. The pitch and problem statements remain accurate.

### Key results (estimates, to be checked at TRL 3)

| Quantity | Estimate | Requirement |
| --- | --- | --- |
| Chamber volume and capacity | 36 L, six sensor bays | R10 met |
| Heat leak with jacket | about 1.0 W/K | Basis for R1 |
| Temperature range | 10 to 40 °C in a room at 25 °C or below; lowest about 15 °C in a 30 °C room | R1 **not met** in warm rooms |
| Humidity range | 20 to 85 % RH; 1.2 g of water for 20 to 85 % at 40 °C | R2 met, with door panel needed at 40 °C and 85 % RH |
| Four-point sweep plus particle run | about 6 h | R11 met |
| Smoke decay 300 to 5 µg/m³ | about 30 min | R7 met |
| Peak power | about 70 W from a 12 V external supply | R15 met |
| Size and mass | about 610 x 470 x 350 mm, about 10 kg | R13 **not met** on length by 10 mm |
| Parts cost | about $396 | R12 **not met** (budget $300) |

Requirements not met or at risk: R1 (cooling in warm rooms), R5 (temperature reference has no calibration certificate), R8 (particle traceability needs a collocation site), R12 (cost), R13 (footprint, by 10 mm). R3, R4 and R14 stay open until TRL 3.

### Proposed, awaiting Amish

*Update 2026-09-25: items 1 to 6 are Decided by Amish, 2026-09-25: go with recommendation (CLR-DDR-002). Item 7 remains Proposed, awaiting Amish.*

1. **Budget.** Parts are about $396 against `budget_usd: 300`. Options: (a) raise to $400; (b) a core version without CO2 (drop the SCD30 and soda lime, about $329); (c) keep $300 by also dropping the second SHT45 and the insulation jacket, which weakens R4 and R1. Recommendation: (a). `project.yaml` is unchanged.
2. **Reference strategy.** Transfer references (SHT45, SCD30, collocated SPS30) checked against salt fixed points, an ice point and field collocation, rather than certified instruments. Recommendation: adopt, and state the uncertainty chain in every report.
3. **Cooling limit (R1).** Options: accept 10 °C only in rooms at 25 °C or below; add a second Peltier module (about $30, supply to 20 A); add an ice-water exchanger for cold runs. Recommendation: accept the limit for the first build.
4. **Test aerosol.** Incense smoke decay (recommended) versus a salt nebulizer or test dust. Reports would state the aerosol type.
5. **Gas scope.** AirStreet's README says it is "calibrated on CalRig" for PM2.5 and NO2. NO2 needs a certified gas cylinder, dilution and toxic gas handling. Options: a later add-on repo, a partner lab, or field collocation only for NO2. Recommendation: field collocation only for now, and align AirStreet's wording. Not changed in AirStreet.
6. **Door condensation.** Insulated door panel for hot, humid points (recommended), a double-glazed door or a heated film.
7. **Collocation partner** for the transfer SPS30: a regulatory monitoring station, a university site or an AQ-SPEC style program.

### Safety concerns

- Peltier hot side at 60 to 70 °C beside a combustible acrylic shell; independent thermal cut-offs and guarding are required.
- Water and electronics share the base: keep electronics outside and below the chamber, and use only a certified external 12 V supply.
- Smoke contains fine particles and some carbon monoxide; clear the chamber through the HEPA loop before opening, and ventilate the room.
- Soda lime (corrosive) and lithium chloride (harmful if swallowed) need gloves, eye protection and labeling.
- Exhaled-air CO2 checks need a single-user bag and filter.

### Gaps against the brief

- None known. The EPA numeric PM2.5 targets are cited through the EPA sensor loan program QAPP, which quotes the 2021 report, because the report PDF itself was not read in full.

### Recommended next step

Review this note and the media. If approved, run `/advance-trl3` to write the calculation note (heat balance with a real Peltier curve, moisture and condensation check, reference uncertainty budget, decay model with wall deposition), build the parametric model with STEP export and the drawing sheet, and complete the priced BOM.

## Session 2026-09-25: TRL 3

Amish's instruction for this batch (2026-09-25): "you know the drill, nothing gets past TRL 3". He did not review this repo's TRL 2 items one by one, so the recommendations were adopted for TRL 3 work, open for his review, and nothing here is recorded as decided by him.

### What was done

- `docs/decisions/0001-trl2-review-decisions.md` (CLR-DDR-001 v0.1): items A1 to A6 adopted as recommended for TRL 3 under Amish's 2026-09-25 instruction, open for his review; O1 (collocation partner) stays "Proposed, awaiting Amish".
- `docs/04-calcs/01-sizing.md` (CLR-CAL-001 v0.1) and `docs/04-calcs/sizing.py`: geometry and mass, heat balance with a thermoelectric module model, moisture, condensation and conditioners, PI stability simulation, bay uniformity, reference uncertainty budgets, particle clean-down and decay, CO2, throughput, power and cost, with a results table for R1 to R18. The script imports the model's PARAMS and part solids and reads the BOM and `project.yaml`.
- `cad/src/model.py`: parametric build123d model (massing plus: chamber, full jacket and door panel, Peltier opening and sinks, six bays at the R10 head size, ports, conditioning column, base parts). Exports `cad/step/` and `cad/stl/` `calrig-assembly`, `chamber` and `conditioning`.
- `cad/src/sheets.py` and `cad/drawings/CLR-DWG-001.svg`, `.pdf`, `.png`: general arrangement, Rev P1, "CONCEPT, NOT FOR FABRICATION" and "PRELIMINARY, NOT FOR FABRICATION". The concept blueprint stays CLR-DWG-010.
- `bom/bom.csv` (every line priced with a supplier type; total $404) and `bom/bom-notes.md`.
- `cad/src/concept_media.py` now builds from `model.py`; all media refreshed (`hero`, `cutaway`, `exploded`, `flow`, `concept-blueprint`, `model.glb`, `viewer.html`) and checked by eye; temporary `_views` folders deleted.
- CLR-PRB-001, CLR-PRC-001 and CLR-REQ-001 bumped to v0.3 (R1 redefined per A3; statuses and numbers from CLR-CAL-001; design choices shown as adopted for TRL 3, open for review). `README.md` TRL badge, links and performance paragraph updated; the required sections are unchanged. `project.yaml`: `trl: 3`, `trl_target: 3`, evidence listed. Pitch, problem and `budget_usd` unchanged.

### Requirement status (CLR-CAL-001, Table 4)

Met 10, at risk 3, not met 4, not verifiable at TRL 3 1.

- **Not met:** R2 (85 % RH at 20 °C cannot be held in rooms above about 19 °C: the inner Peltier sink runs 1.2 K below the dew point and condenses about 8 g/h against 0.7 g/h from the bubbler); R8 (no collocation site yet); R12 ($404 against $300, and $4 over the proposed $400); R13 (mass 13.4 kg against 12 kg; 600 x 500 x 374 mm now fits).
- **At risk:** R4 (±0.18 °C at the EPA points with the 120 mm fan, ±0.42 °C at 10 °C); R5 (0.14 °C with the typical SHT45 tolerance, 0.24 °C if it is 0.2 °C); R6 (2.0 % RH, no margin).
- **Not verifiable at TRL 3:** R14 (software).
- **Met:** R1 (8.9 °C in a 25 °C room, 13.3 °C in a 30 °C room), R3 (idealized model), R7 (28 min decay), R9, R10, R11 (5.6 h), R15 (89 W, 7.4 A), R16, R17, R18.

Design changes made by the calculations: jacket on all faces but the door (conductance 0.82 W/K); 120 mm mixing fan; bubbler foam sleeve, 0.3 L fill and a trace-heated outlet line; base trimmed to 600 x 500 mm with the chamber moved so the aerosol valve stays on it. TRL 2 numbers corrected: gains 6.7 W (was 4 W), peak power 89 W (was 70 W), bus 7.4 A (was 6 A), mass 13.4 kg (was 10 kg), sweep 5.6 h (was 6 h), cost $404 (was $396).

### Decisions recorded (CLR-DDR-001)

*Update 2026-09-25: A1 to A6 are now Decided by Amish, 2026-09-25: go with recommendation (CLR-DDR-002).*

Each adopted as recommended for TRL 3 under Amish's 2026-09-25 instruction, open for his review: A1 budget rise to $400 (recorded only; `budget_usd` stays $300), A2 transfer references, A3 accept the cooling limit (R1 redefined), A4 incense smoke decay, A5 NO2 by field collocation only, A6 insulated door panel.

### Still awaiting Amish

*Update 2026-09-25: items 3, 4 and 5 are Decided by Amish, 2026-09-25: go with recommendation (CLR-DDR-002). Items 1 (budget figure above $400) and 2 (O1) have no recommendation and remain Proposed, awaiting Amish.*

1. **Budget figure.** $300 in `project.yaml`; $400 proposed; design now $404. Options: accept $404 or about $410; drop CO2 for a core version at about $337; or find $4 of savings. **Decided by Amish, 2026-09-26: budget set to $412** (CLR-DDR-002).
2. **Collocation partner (O1)** for the transfer SPS30. No recommendation.
3. **Inner Peltier sink (R2).** Proposed: a larger inner fin block, about 0.20 K/W, so the 20 °C, 85 % RH point runs in rooms up to about 28 °C. Alternative: run that point only in a room below 19 °C. Recommendation: the larger sink, about $5 to $10 more.
4. **Mass (R13).** Options: carry the supply and salt jars separately (about 12.2 kg), use 5 mm acrylic, or relax R13 to 14 kg. Recommendation: relax to 14 kg; it is a bench rig.
5. **Reference temperature (R5).** Options: accept the risk, or add a certified thermistor probe or a second fixed point. Recommendation: a certified probe, if the budget allows.

### Cross-repo notes

- CalRig depends on no shared component. Siblings that use it: AirStreet (PM, T and RH; NO2 by field collocation, which matches A5; its pitch line still says "calibrated on CalRig" and is AirStreet's to change), DustBadge (low-level smoke checks only, consistent), HeatMap Node, SlopeWatch, TwinKit, FieldNode users.
- Possible conflict, not edited: HeatMap Node's 150 mm black globe and SlopeWatch's 34 x 130 mm capsule exceed the 90 x 70 x 50 mm bay size in R10. Both fit the chamber (244 mm clear above the tray) if they take two bays; R10 could add a "large item" case.
- H2Guard suggested a hydrogen span check on CalRig. That is outside A5 and is not adopted.

### Safety concerns

- Peltier outer sink up to about 50 °C and inner sink about 46 °C when heating; cut-offs at 70 °C hot side and 50 °C air stay required. Keep the sinks clear of the acrylic.
- Condensate on the inner sink at cold and humid points: a drip tray and drain are needed, and electronics stay below and outside the chamber.
- The new trace heater and bubbler pad each need a thermistor and must be switched off by the same cut-off.
- Smoke (fine particles and some CO), soda lime and lithium chloride precautions as at TRL 2.

### Gaps and notes

- The EPA PM2.5 target values are still cited through the EPA sensor loan program QAPP. WebFetch confirmed the EPA/600/R-20/280 record page but not the values in the PDF; the flag stays. WebSearch was not available. The SHT45 product page confirms ±0.1 °C and 1 % RH typical; the maximum tolerance and hysteresis used in CLR-CAL-001 are stated assumptions.
- No TRL 4 material exists in the repo (`firmware/` and `electronics/` are empty; `build-log/README.md` is the stock header only).
- The kit's cutaway cuts at the mean Y of the parts, which keeps the tray, mast, fan and Peltier in the section; the sensors under test fall mostly in the removed half. Left as is.
- `cad/drawings/.gitkeep` was removed now that the folder holds the drawing.

### Recommended next step

Review CLR-DDR-001 and the five items above. TRL 4 is on hold by Amish's instruction; nothing further should be done until he lifts it. For the record, TRL 4 would need a built chamber, a lab test report (TST, `environment: lab`) with logged temperature, humidity, uniformity and decay runs, salt and ice-point reference checks, and build log entries.

## Session 2026-09-25: recommendations accepted

Amish wrote on 2026-09-25: "i accept all your recommendations, go with them across all repos." Every item with a recommendation is now **Decided by Amish, 2026-09-25: go with recommendation**, recorded in `docs/decisions/0002-recommendations-accepted.md` (CLR-DDR-002 v0.1). CLR-DDR-001 is bumped to v0.2 with A1 to A6 marked decided.

### Decisions applied and what changed

| Item | Decision | Before | After |
| --- | --- | --- | --- |
| Budget (A1) | Raise `budget_usd` to $400 | $300 | $400 in `project.yaml`; design $412, R12 still not met |
| Reference strategy (A2), cooling limit (A3), test aerosol (A4), door panel (A6) | As recommended | Adopted for TRL 3, open for review | Decided; wording only |
| Gas scope (A5) | NO2 by field collocation only; align AirStreet | Adopted, open for review | Decided; AirStreet wording is a cross-repo action |
| Inner Peltier sink (R2) | Larger inner fin block, about 0.20 K/W | 30 x 80 x 90 mm, 0.45 K/W; sink 16.2 °C at 20 °C, 85 % RH; dry below a 19 °C room; R2 not met | 45 x 120 x 110 mm, 0.20 K/W; sink 18.3 °C (0.9 K above dew point); dry up to a 28 °C room; R2 met |
| Mass (R13) | Relax to 14 kg | 12 kg limit, 13.4 kg, not met | 14 kg limit, 13.6 kg, met |
| Reference temperature (R5) | Certified probe if the budget allows | No probe | Budget does not allow ($412 against $400); no probe added; R5 at risk |

Knock-on numbers from CLR-CAL-001 v0.2: BOM line 5 $30 to $38, total $404 to $412; lowest chamber temperature 8.9 to 6.7 °C (25 °C room) and 13.3 to 11.1 °C (30 °C room); cooling to 10 °C 3.7 to 2.4 h; sweep plus particle run 5.6 to 5.5 h; peak power 89 to 90 W (7.5 A); core version without CO2 $337 to $345.

Files changed: `project.yaml` (budget, DDR-002 in evidence), `README.md` (budget, concept paragraph, key components, "What sparked the idea" rewritten), CLR-PRB-001 v0.4, CLR-PRC-001 v0.4, CLR-REQ-001 v0.4, CLR-CAL-001 v0.2 and `sizing.py`, CLR-DDR-001 v0.2, new CLR-DDR-002 v0.1, `cad/src/model.py` (STEP and STL re-exported), `cad/src/sheets.py` (CLR-DWG-001 Rev P2), `cad/src/concept_media.py` (key figures; all media regenerated and checked by eye), `bom/bom.csv`, `bom/bom-notes.md`. All PDFs, drawings and media re-rendered with the Design Molecule footer.

### Requirement status (CLR-CAL-001 v0.2)

Met 12, at risk 3, not met 2, not verifiable at TRL 3 1.

- **Not met:** R8 (no collocation site; O1 open), R12 ($412 against $400).
- **At risk:** R4 (±0.42 °C between bays at 10 °C), R5 (0.24 °C if the SHT45 tolerance is 0.2 °C; probe deferred), R6 (2.0 % RH, no margin).
- **Not verifiable at TRL 3:** R14 (software).
- **Met:** R1, R2 (now), R3, R7, R9, R10, R11, R13 (now), R15, R16, R17, R18.

### Still awaiting Amish

1. **Collocation partner (O1)** for the transfer SPS30. No recommendation.
2. **Budget figure above $400 (O2).** Design is $412. Accept about $412, drop CO2 for a core version at about $345, or find $12 of savings. No recommendation. **Decided by Amish, 2026-09-26: budget set to $412** (CLR-DDR-002).

### Cross-repo actions

- **AirStreet:** align the pitch line "calibrated on CalRig" with NO2 by field collocation only (decision A5). Not edited from this repo.
- Note, no decision: HeatMap Node's 150 mm globe and SlopeWatch's capsule exceed the R10 bay size; they fit the chamber if they take two bays.

### TRL

`trl: 3`, `trl_target: 3`. TRL 4 remains on hold by Amish's instruction: no build, test, purchasing, PCB or firmware work was done. The certified probe (D9) would be a purchase and is not bought.

## Session 2026-09-26: budget approved

Amish wrote on 2026-09-26: "i approve all the budget items." Budget set to $412 to cover the priced BOM: decided by Amish, 2026-09-26. This closes O2.

- `project.yaml` `budget_usd` $400 to **$412**. The priced BOM is unchanged at $412 (18 lines).
- R12 (cost): target $400 to $412; status **Not met to Met**. Requirement status is now met 13, at risk 3, not met 1 (R8, collocation site), not verifiable at TRL 3 1 (R14).
- The certified temperature probe (D9, "if the budget allows") is still not added: the new budget has no headroom for it, so R5 stays at risk.
- Files changed: `project.yaml`, `README.md`, CLR-PRB-001 v0.5, CLR-PRC-001 v0.5, CLR-REQ-001 v0.5, CLR-CAL-001 v0.3 (`sizing.py` rerun), CLR-DDR-002 v0.2, `bom/bom-notes.md`, `cad/src/concept_media.py` (blueprint key figure); media and PDFs regenerated, temporary `media/_views*` folders deleted.
- Still awaiting Amish: O1 (collocation partner). `trl: 3` and `trl_target: 3` are unchanged; TRL 4 remains on hold.

## Session 2026-09-26: product appearance model and photoreal renders

Amish chose CalRig for the first batch of product renders on 2026-09-26. This session adds an appearance model for photoreal product shots. It does not change the design, `cad/src/model.py`, the BOM or any controlled document.

### What was added

- `cad/src/product_model.py`: `product_parts()` (99 parts: 65 shell, 31 internal, 2 accessory, 1 context), `TITLE` and `RENDER_VIEWS` (hero, exploded and a detail view without the bench). Every main dimension, position and interface is taken from `PARAMS`, `derived()` and `build_parts()` in `model.py`; the clear chamber shell is the `model.py` solid itself.
- Finished-product detail: the insulation jacket as five filleted panels with seams where they meet (bottom, top, back, left, right, as in `model.py`), a teal name plate and a lit status light on the top band; the clear door with a printed dark border, silicone gasket line, two draw latches with levers and rivets and the sensor lead gland; inside, the perforated six-bay tray with its cable rail and hub connectors, six example sensor heads in three styles with serial labels and lit status lights, the reference cluster on its printed mast with a teal vented front plate, the guarded 120 mm mixing fan and the finned inner Peltier block; outside, the finned outer sink and guarded 92 mm fan, the foam-sleeved bubbler with glass jar and knurled lid, the dryer column with indicating silica gel, the aerosol port with ball valve, lever and Luer port, the HEPA housing, controller, power supply and DC lead, four salt jars with coloured lids and labels, base plate screws and the removable door panel with a pull handle (accessory group, exploded view only).
- Context: a compact lab bench top (800 x 600 mm) under the 600 x 500 mm base plate.
- `README.md`: hero image now points to `media/render-hero.png`, and the links line starts with the exploded render. The render files are produced later by the orchestrator.

### Differences from model.py (appearance only)

Each item is **Proposed, awaiting Amish**.

1. **Faced, rounded jacket.** The XPS jacket is drawn with a smooth light-grey facing, 12 mm vertical and 10 mm top corner radii and visible panel seams; `model.py` has bare, square XPS panels. Recommendation: keep this look for renders only and decide on a facing (for example thin PVC sheet) at TRL 4, when its cost can be checked against the $412 budget.
2. **Base plate in dark HDPE** with 22 mm corner radii and four screw heads. The BOM allows plywood or HDPE. Recommendation: HDPE, since the rig holds water.
3. **Front status light and name plate** on the top band of the jacket, driven by the controller (BOM 13). Not in `model.py` or the BOM. Recommendation: adopt; a single LED and a label add little cost and show run state without opening the rig.
4. **Door details.** Printed border (22 mm), gasket line and a lead gland at the lower right of the door. BOM line 2 lists the gasket and gland but `model.py` gives no gland position. Recommendation: adopt the border (it hides the shell edges and wiring) and confirm the gland position at TRL 4.
5. **Door panel pull handle.** Not in `model.py` or the BOM. Recommendation: adopt; the panel is removed for every warm, dry point.
6. **Bubbler and dryer.** The foam sleeve stops 16 mm below the jar top so the glass and a knurled lid show; the overall height is unchanged. The wet and dry lines are drawn as round tubes (12 mm sleeved and 9 mm silicone) on the `model.py` routes instead of square bars. Recommendation: accept as drawn.
7. **Fan guards** on the outer 92 mm fan and the mixing fan, as the precis and BOM line 6 require; `model.py` shows plain boxes. Recommendation: accept.
8. **Example sensor heads** in three housing styles, each inside the `model.py` bay envelope, with lit status lights. They are example payload, not BOM items. Recommendation: accept.
9. **Aerosol valve lever** stands about 19 mm above the `model.py` valve envelope. Recommendation: accept; it is within the overall footprint.

### Checks

All parts are valid solids and tessellate; `python .kit/product_export.py` and `python .kit/render.py --check` pass. Matplotlib previews of the three views were checked by eye (clear parts left out of the previews).

### TRL

This is an appearance model only: no tolerances, no fabrication detail. `trl: 3` and `trl_target: 3` are unchanged, and TRL 4 remains on hold. Still awaiting Amish: O1 (collocation partner) and items 1 to 9 above.

## Session 2026-09-27: kit 1.5.0 and image quality

- Kit 1.5.0 synced: STANDARDS v1.5 (sections 12 to 15: product renders, storefront images and image quality, public release, authorship and signing), `.kit/cards.py`, `.kit/image_qc.py`, `.kit/release_gate.py`, issue templates, and the `/render-product` and `/release` commands. `CLAUDE.md` now matches `.kit/CLAUDE.md`.
- Every `media/render-*.png` recaptioned from its original render with the new layout: the title, concept label and repository sit in a band above the render and the view note in a band below it, each line wrapped to the image width, so no text overlaps other text or the render or runs off the image. `media/card.png` and `media/social-preview.png` regenerated with the same rules.
- `python .kit/image_qc.py` and `python .kit/release_gate.py` pass. trl stays 3.

## Session 2026-10-01: design for construction and illustrated build plan (BLD-001)

Amish approved the build plan format on 2026-09-30 and asked for it across all repos, with outstanding decisions kept out of the build plan and in a separate design decisions register. Kit 1.7.0 was installed (`.kit/`, `.claude/commands/`, `CLAUDE.md`). Instruction followed: "If you are realising that the design cannot be built as per concept - fix the design assumptions to match and be physically feasible as you draw the illustrations."

### What was done

- `cad/src/model.py`: rebuilt as separate components (`build_components()`), with the BOM groups kept for the calculation note, drawing and media (`build_parts()`), and 79 build123d constructability checks (`python cad/src/model.py --check`): all pass. STEP and STL re-exported.
- `docs/decisions/0003-design-for-construction.md` (CLR-DDR-003 v0.1, Draft): every change, made under Amish's 2026-09-30 instruction to make the design physically buildable; open for his review.
- `cad/src/build_plan_media.py`: overview, eleven making sketches (CLR-DWG-101 to 111), nine joint close-ups, thirteen step pictures, and four diagrams (wall hole positions, base layout, air loops, block-level wiring), in `docs/05-build-plan/` and `cad/drawings/`.
- `docs/05-build-plan.md` (CLR-BLD-001 v0.1) and `docs/06-design-decisions.md` (CLR-DEC-001 v0.1).
- `bom/bom.csv` (lines 1, 2, 3, 4, 5, 10, 13 and 15 revised; new line 19) and `bom/bom-notes.md`; CLR-CAL-001 v0.4 (`sizing.py` re-run), CLR-REQ-001 v0.6, CLR-PRC-001 v0.6; CLR-DWG-001 Rev P4; concept media regenerated (`hero`, `cutaway`, `exploded` with line 19, `flow`, `concept-blueprint`, `model.glb`, `viewer.html`).
- `project.yaml`: `design_state: constructable`; build plan, register, DDR-003 and overview picture added to `trl_evidence`. `budget_usd` unchanged at $412. README: build plan link, "Building the prototype" section, performance paragraph updated.

### Design changes made for construction (CLR-DDR-003)

1. **Door (P1):** a 450 x 350 mm acrylic front frame welded to the shell gives the gasket a 25 mm face; the door is 430 x 330 mm; four draw latches (was two) on frame tabs hook keepers on the door.
2. **Door panel (P2):** 406 x 330 mm on the door between the latches, on four hook-and-loop pads (was a loose full-front panel).
3. **Heat pump (P3):** both sink bases clamp the right wall with four M4 screws through rigid sleeves in the jacket.
4. **Mixing fan (P4):** on four welded 15 mm spacers on the back wall (was floating).
5. **Sensor tray (P5):** 10 mm legs (were 5 mm posts); 87-hole perforation defined.
6. **Reference mast (P6):** printed 20 mm mast standing on the floor, screwed to the tray rail (was floating behind the tray).
7. **Conditioning loop (P7):** three 12 mm bulkheads in the right wall, including a new suction port; two pumps on the base; dryer line now reaches the column; printed dryer socket; bubbler 10 mm further back.
8. **HEPA loop (P8):** two 12 mm bulkheads in the back wall into the HEPA unit (it had no connection).
9. **Leads (P9):** two M20 multi-hole cable glands in the back wall instead of one gland in the door; the hub moves to the controller.
10. **Drip tray and drain (P10):** welded tray under the inner sink, 6 mm drain bulkhead, line to a 250 mL bottle (in the precis but not in the model).
11. **Aerosol port (P11):** 16 mm bulkhead sealing in a 16 mm hole (was a stub floating in a 20 mm hole).
12. **Salt jars (P12):** printed rack.
13. **Knock-on:** base 9 mm sealed birch plywood (was 12 mm plywood or HDPE) to stay within 14 kg; overall height 371 mm; cut-offs hold in a relay on the Peltier and heater supply.

### Key results

- Mass 13.83 kg against 14 kg (R13 met, 0.17 kg margin). Value-engineering target $412 (a hypothetical control target, not a limit); estimated cost of the constructable design $439 on 19 lines ($27 over the target): **R12 over the value-engineering target**. Heat capacity 8.7 kJ/K; 10 °C reached in 2.5 h; every other result unchanged.
- Requirement status (CLR-CAL-001 v0.4): met 12, at risk 3 (R4, R5, R6), not met 1 (R8), over the value-engineering target 1 (R12), not verifiable at TRL 3 1 (R14).

### Proposed, awaiting Amish

All in the design decisions register (CLR-DEC-001): review of CLR-DDR-003 (recommend accept); mass margin (accept, weigh at TRL 4); base material (sealed plywood); plus the items carried over (savings worth trying against the value-engineering target are in the register's value engineering section): collocation partner (O1), appearance model items, report format, large sensor heads in R10.

### Stale images (made on Amish's Mac, not regenerated here)

`media/render-*.png`, `media/card.png`, `media/social-preview.png` and `cad/src/product_model.py` still show the concept door, two latches, the full-front door panel, the 12 mm base and no bulkheads, glands or drain. They need updating on Amish's Mac.

### Safety concerns

- The new drain and drip tray keep condensate inside the right wall away from the electronics; the electronics stand behind the chamber.
- Cut-offs now drive a relay so a small bimetal switch is not asked to break the Peltier current; to be checked in section 5 of the build plan.
- Solvent cement and laser-cut acrylic fumes added to the safety stops.

### Recommended next step

Amish reviews CLR-DDR-003 and the register, and the value engineering section. TRL 4 (building and testing to CLR-BLD-001) stays on hold.

## Session 2026-10-02: open-decision recommendations approved

Amish, 2026-10-02: "i approve your recommendations for all 555 open decisions." This approves the recommendation for every open decision in the design decisions register. 7 decisions were recorded: each moved to Decisions made, dated 2026-10-02, with the approved recommendation and its record. trl stays 3; no build or test work was done, and the CAD model, BOM quantities and prices, and pictures were not changed.

### Documents changed

- `docs/06-design-decisions.md` (CLR-DEC-001 v0.3): the seven open decisions moved to Decisions made; Open decisions now reads none
- `docs/decisions/0003-design-for-construction.md` (CLR-DDR-003 v0.3): status accepted (Tables 1 and 2, A2 and A3) with Amish's words; A2 records the 5 mm acrylic top as the first fallback, A3 the plywood renders; A1 stays proposed
- `docs/decisions/0001-trl2-review-decisions.md` (CLR-DDR-001 v0.3): O1 (collocation partner) decided
- `docs/decisions/0002-recommendations-accepted.md` (CLR-DDR-002 v0.3): O1 (collocation partner) decided
- `docs/03-requirements.md` (CLR-REQ-001 v0.8): R8 names the first candidate site (status unchanged, not met); R10 adds the large item case; R14 states the EPA 2021 report basis and uncertainty chain
- `docs/04-calcs/01-sizing.md` (CLR-CAL-001 v0.6): requirement table wording for R8, R10 and R14; no result changed
- `docs/02-concept.md` (CLR-PRC-001 v0.8): open questions on the particle reference and report format answered; large heads take two or four bays
- `docs/01-problem.md` (CLR-PRB-001 v0.6): open questions on collocation and report format answered
- `README.md`: concept paragraph: larger heads take two or four of the six bays
- `bom/bom-notes.md`: base material and the adopted appearance items noted; no quantity or price changed
- PDFs regenerated with `python3 .kit/render.py`; superseded PDF versions removed by the render.

### Follow-up actions to carry approved decisions into the design

1. Decision 3 (pictures): Redraw the photoreal renders, `media/card.png` and `media/social-preview.png` from `cad/src/product_model.py` with the 9 mm sealed birch plywood base instead of dark HDPE (on Amish's Mac)
2. Decision 5 (model): Add the front status light and name plate, the printed door border and the door panel pull handle to `cad/src/model.py` and its constructability checks; draw no gland in the door
3. Decision 5 (drawings): Show the status light, name plate, door border and pull handle on CLR-DWG-001 and the door and door panel making sketches
4. Decision 5 (bom): Add BOM lines or line changes for the status light and its controller wiring, the name plate, the door border and the pull handle, and price them
5. Decision 5 (pictures): Regenerate the build plan pictures for the door, door panel and controller steps, and update the appearance model renders (four latches, glands in the back wall, jacket facing in renders only)
6. Decision 5 (docs): Add the status light wiring and pull handle to the build plan text (CLR-BLD-001) once they are in the model
7. Decision 7 (model): Add a model check that a 192 x 152 mm head fits a 2 x 2 block of bays and a 192 x 70 mm head two bays side by side, within the 244 mm clear height
8. Decision 7 (calcs): Add the large item case to `sizing.py` and CLR-CAL-001 section A, and confirm the R10 status
9. Decision 6 (docs): Define the per-sensor report template (R14) to the US EPA 2021 targets and protocol, with the uncertainty chain from the fixed points and the collocation record

### Points found in the review

- The cross-repo note says the large heads fit "if they take two bays"; the 150 mm HeatMap Node globe spans both 70 mm bay rows and two columns of the 318 x 176 mm tray, so it takes four bays, not two.
- The 2026-09-26 appearance note recommends an HDPE base (item 2) and a door gland (item 4); both are now superseded by DDR-003 (9 mm plywood for R13, glands in the back wall) and the appearance model still shows two latches, not four.
- R12 cost ($439 against the $412 target) is not an open register item; DDR-003 A1 recommended keeping the design and re-pricing at purchase. Confirm Amish is content to leave it in the value engineering section.

## 2026-10-02: Approved follow-ups carried out

Amish, 2026-10-02, approved carrying out every follow-up action from the open-decision sign-off ("APPROVED CHANGES, COMPLETE THESE") and preparing the render scenes. TRL stays 3; nothing was built or tested.

### Follow-ups

| # | Follow-up | Done | What changed |
| --- | --- | --- | --- |
| 1 | Decision 3: renders, card and social preview with the 9 mm plywood base | Scenes ready | `cad/src/product_model.py` draws the base as sealed birch plywood from the `model.py` solid; render scenes exported (below). The photoreal renders, `media/card.png` and `media/social-preview.png` are made next on Amish's Mac |
| 2 | Decision 5: status light, name plate, door border and pull handle in `model.py`; no gland in the door | Done | Front badge (printed, 200 x 30 mm, lip on the front frame's top edge) with a 12 V panel light and the name plate; status light lead along the jacket top and back panel to the controller; 22 mm printed border on the door, cut round the keepers; printed pull handle on the door panel. No gland in the door. 37 new checks; 116 of 116 pass |
| 3 | Decision 5: show them on CLR-DWG-001 and the door and door panel sketches | Done | CLR-DWG-001 Rev P5 (door panel fitted, callouts and notes); CLR-DWG-110 Rev P2 (border); CLR-DWG-111 Rev P2 (door panel and pull handle); new CLR-DWG-112 (front badge) |
| 4 | Decision 5: BOM lines for the status light and wiring, name plate, door border and pull handle | Done | Line 2 border ($17 to $20), line 3 pull handle ($17 to $18), line 13 status light output (no price change), new line 20 front badge, status light, name plate and lead ($5.50); basis for each price in the line notes and `bom/bom-notes.md` |
| 5 | Decision 5: build plan pictures for the door, door panel and controller steps; appearance model with four latches, back-wall glands, jacket facing in renders only | Done | New step 12 (badge and lead to the controller), steps 13 (door with border) and 14 (door panel with handle), joint 10, overview (26 components), wiring diagram; `product_model.py` rebuilt from the `model.py` solids (four latches and keepers, back-wall glands and bulkheads, no door gland, faced jacket) |
| 6 | Decision 5: status light wiring and pull handle in the build plan text | Done | CLR-BLD-001 v0.2: section 3.15 (front badge and status light), wiring item 8, pull handle in 3.14, border in 3.13, step 12 and renumbered steps, first checks for the status light and large heads |
| 7 | Decision 7: model check for 192 x 152 mm heads on 2 x 2 bays and 192 x 70 mm heads on two bays within the clear height | Done | `large_heads()` in `model.py`: every pair (4) and block (2) position at 234 mm tall (10 mm under the chamber top); 18 checks pass (on the tray, inside its outline, 5 mm or more from walls, fan, inner sink, drip tray, aerosol port and references) |
| 8 | Decision 7: large item case in `sizing.py` and CLR-CAL-001 section A; R10 status | Done | New result [A4]; **R10 moves from met for six heads to met including the large item case** |
| 9 | Decision 6: per-sensor report template (R14) to the US EPA 2021 targets, with the uncertainty chain | Done | CLR-PRC-001 v0.9, new section and Table 4: identification, run conditions, reference status, fitted correction, EPA metrics against their targets, enhanced conditions, uncertainty chain (ice point, salt fixed points, collocation record), limits of use. R14 stays not verifiable at TRL 3 (software not written) |

### Model and checks

- `python cad/src/model.py --check`: 116 of 116 pass (was 79). New: border on the door and clear of the gasket, keepers through the border cut-outs, pull handle on the panel and clear of door, latches and badge, badge on the jacket top and on the frame's top edge and clear of door, panel and latches, light bezel and name plate on the badge, lead from the light, clear of the badge hole, along the jacket, onto the controller and clear of glands, HEPA bulkheads, heat pump, dryer and supply, and the 18 large-head checks.
- STEP and STL regenerated. Overall 600 x 500 x 383 mm (the badge top is now the highest point; the jacket top is at 371 mm).

### Requirement status changes (CLR-CAL-001 v0.7, CLR-REQ-001 v0.9)

- R10: met for six heads to **met**, including the large item case.
- R12: over the value-engineering target by USD 27 to **over by USD 36.50**. Value-engineering target: USD 412. Estimated cost of the constructable design: USD 448.50 (USD 36.50 over the target). `budget_usd` unchanged.
- R13: still met; 600 x 500 x 383 mm, 13.92 kg, margin 0.08 kg (was 0.17 kg). The 5 mm acrylic top fallback (DDR-003, A2) would recover about 0.15 kg.
- R14: still not verifiable at TRL 3; the report template is now defined.
- Counts unchanged: met 12, at risk 3 (R4, R5, R6), not met 1 (R8), over the value-engineering target 1 (R12), not verifiable at TRL 3 1 (R14).

### Documents changed and new versions

- `cad/src/model.py`, `cad/src/sheets.py` (also corrected its view mapping to the kit layout, so the dimensions sit on the views), `cad/src/concept_media.py`, `cad/src/build_plan_media.py`, `cad/src/product_model.py`; `cad/step/`, `cad/stl/`
- `docs/04-calcs/sizing.py` and `docs/04-calcs/01-sizing.md` CLR-CAL-001 v0.7
- `docs/03-requirements.md` CLR-REQ-001 v0.9; `docs/02-concept.md` CLR-PRC-001 v0.9
- `docs/05-build-plan.md` CLR-BLD-001 v0.2; `docs/06-design-decisions.md` CLR-DEC-001 v0.4 (value engineering restated; items 8 and 9 to confirm); `docs/decisions/0003-design-for-construction.md` CLR-DDR-003 v0.4 (consequences)
- `bom/bom.csv` (lines 2, 3, 13, new 20) and `bom/bom-notes.md`; `README.md`

### Pictures regenerated (each looked at)

- `cad/drawings/CLR-DWG-001` Rev P5, CLR-DWG-110 Rev P2, CLR-DWG-111 Rev P2, CLR-DWG-112 P1 (new).
- `docs/05-build-plan/overview.png`, `joint-10.png` (new), `step-12.png` to `step-14.png`, `wiring.png`; the other joints, steps and the air loop diagram were redrawn by the same run with no change of content.
- `media/hero.png`, `exploded.png` (callout 20 added; HEPA unit and fittings moved so their callouts no longer touch others), `cutaway.png`, `flow.png`, `concept-blueprint.png`, `.pdf` and `.svg` (key figures: 383 mm, 13.9 kg, cost in the value-engineering wording), `model.glb`, `viewer.html`.
- `python3 .kit/drawing.py --check-text cad/drawings/*.svg media/concept-blueprint.svg`: no hits.

### Render scenes (appearance model)

- `cad/src/product_model.py` now takes most parts directly from `build_components()` in `model.py`: plywood base, faced jacket with the model's holes, front frame, drip tray and spacers, door with printed border, gasket, four latches and keepers, clamped Peltier sinks and screws, mixing fan on its spacers, perforated acrylic tray, printed mast, five bulkheads, two back-wall glands, drain line and bottle, two pumps and suction line, dryer socket, jar rack, front badge with name plate and lit status light, the light's lead, and the door panel with its pull handle (accessory). `RENDER_VIEWS` keeps hero, exploded and detail.
- Exported with `python3 .kit/export_views.py /home/claude/renders/calrig`: `calrig__hero`, `calrig__exploded` and `calrig__detail` (.npz and .json each) and `calrig__jobs.json`.
- Not rendered here: `media/render-*.png`, `media/card.png` and `media/social-preview.png` are made next on Amish's Mac.

### Appearance deviations (Proposed, awaiting Amish)

1. Jacket facing with rounded corners and seams, as decided for renders only; the base plate has 4 mm rounded corners. Recommendation: accept as appearance only.
2. The badge is drawn dark grey, the name plate teal with illustrative print, and the status light lit green; the model has no colour. Recommendation: accept.
3. The tray is drawn as white acrylic with a dark cable rail and six hub connectors; the cable glands are drawn with hex bodies. Recommendation: accept.
4. The lines from the pumps to the bubbler and dryer are not drawn (they are not in the model either); items 6 to 9 of 2026-09-26 (bubbler and dryer details, fan guards, example heads, valve lever) are kept as decided. Recommendation: accept.

### Design detail chosen while carrying out decision 5 (for Amish's information)

- The front of the rig has no free face for a name plate: the front frame covers the jacket's front edges up to 6 mm from the top. The name plate and light therefore sit on a printed badge on the top panel, its lip resting on the frame's top edge. This raises the overall height from 371 to 383 mm (R13 limit 400 mm) and adds about 0.07 kg. If Amish prefers no added height, the alternative is a badge recessed into a notch in the top panel's front edge, at the cost of a harder cut in the foam. Proposed, awaiting Amish, and listed as open decision 1 in the design decisions register; the build plan describes the badge as modelled.

### Cross-repo actions

- HeatMap Node: its R14 note says the assembled 150 mm globe does not fit a CalRig bay. Under CalRig R10 (2026-10-02) a head up to 192 x 152 mm in plan and 234 mm tall fits a 2 x 2 block of four bays, checked in the model, so the assembled globe can be calibrated in CalRig if it is no taller than 234 mm. HeatMap Node's R14 text and status should be reviewed there. Not edited.

### Safety concerns

- The status light runs at 12 V from a switched controller output on a 0.25 mm² lead with a built-in resistor; it adds no new hazard. The lead is clipped along the outside of the jacket, away from the outer sink (about 60 mm clear) and the dryer.
- The pull handle lets the door panel come off without prying at the door near the hot outer sink.

### Recommended next step

Render the product views on Amish's Mac from the exported scenes, then `python .kit/cards.py .`. Decide the badge placement point above and confirm items 8 and 9 in the register when parts are bought. TRL 4 remains on hold.

## 2026-10-02: photoreal renders redone on the constructable design

Rendered with Blender Cycles on Amish's Mac from the updated appearance model (`cad/src/product_model.py`); captioned with `.kit/photo_caption.py`; `media/card.png` and `media/social-preview.png` regenerated with `.kit/cards.py`. Views: hero, exploded, detail. image_qc passes. Appearance deviations are those logged above as proposed, awaiting Amish.

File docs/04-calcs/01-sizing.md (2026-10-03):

---
doc_id: CLR-CAL-001
title: CalRig sizing calculations
project: CalRig
doc_type: Calculation
version: "0.7"
status: Draft
date: '2026-10-02'
author: Amish Chadha
license: CERN-OHL-S-2.0
revisions:
- version: "0.1"
  date: '2026-09-25'
  author: Amish Chadha
  change: First issue for TRL 3 (geometry and mass, heat balance with a thermoelectric model, moisture and condensation, control stability, bay uniformity, reference uncertainty, particle decay, CO2, throughput, power, cost)
- version: "0.2"
  date: '2026-09-25'
  author: Amish Chadha
  change: Recommendations accepted by Amish (DDR-002). Larger inner Peltier sink (0.20 K/W), budget $400, R13 relaxed to 14 kg; all results re-run
- version: "0.3"
  date: '2026-09-26'
  author: Amish Chadha
  change: Budget approved by Amish; budget $412 covers the priced BOM, so R12 is met (CLR-DDR-002 v0.2)
- version: "0.4"
  date: '2026-10-01'
  author: Amish Chadha
  change: Re-run for the constructable design (CLR-DDR-003); 9 mm base, mass 13.8 kg, heat capacity 8.7 kJ/K, BOM $439 on 19 lines, so R12 is not met pending a budget decision
- version: "0.5"
  date: '2026-10-01'
  author: Amish Chadha
  change: Budget treated as a value-engineering target; cost wording only, no number changed
- version: "0.6"
  date: '2026-10-02'
  author: Amish Chadha
  change: 'Requirement table wording follows the decisions of 2026-10-02 (R8 candidate site, R10 large item case, R14 report basis); no result changed'
- version: "0.7"
  date: '2026-10-02'
  author: Amish Chadha
  change: 'Approved follow-ups: large item case checked in the model [A4], R10 met including it; front badge, status light, door border and pull handle added, so height 383 mm and mass 13.92 kg [A3] (R13 still met, 0.08 kg margin); BOM USD 448.50 on 20 lines, USD 36.50 over the value-engineering target [K1]'
---

# CalRig sizing calculations

On paper, CalRig meets twelve of its eighteen requirements, has three at risk, misses one, is over the value-engineering target on cost and has one that cannot be checked at TRL 3. The miss is R8 (particle traceability needs the transfer sensor to be collocated; the first candidate site is named in CLR-DEC-001, but no collocation has been done). R12 is over the target. Value-engineering target: USD 412. Estimated cost of the constructable design: USD 448.50 (USD 36.50 over the target): making the design buildable (CLR-DDR-003) added a front frame, bulkhead fittings, cable glands, a drain and printed holders, and the details adopted on 2026-10-02 added the front badge with its status light and name plate, the printed door border and the pull handle. The three at risk are R4 (bay uniformity at cold set points), R5 (reference temperature uncertainty, which depends on an uncertified sensor tolerance) and R6 (reference humidity uncertainty, 2.0 % RH against a 2 % RH target). R1 is met against the relaxed target of DDR-001: 6.7 °C is reachable in a 25 °C room and 11.1 °C in a 30 °C room. R2 is now met because the inner Peltier sink was enlarged under DDR-002 (0.45 to 0.20 K/W), which keeps it above the dew point at 20 °C and 85 % RH in rooms up to about 28 °C. R13 is met against the relaxed 14 kg limit of DDR-002 (13.9 kg, with a 9 mm base). R10 is met, including the large item case decided on 2026-10-02.

The calculations in v0.1 changed four parts of the TRL 2 concept: the jacket now covers the bottom and the right-hand wall as well; the mixing fan grows from 80 mm to 120 mm; the bubbler jar gets a foam sleeve, a smaller fill and a trace-heated outlet line; and the base plate is trimmed to 600 x 500 mm with the chamber moved so the aerosol valve stays on it. Version 0.2 adds the larger inner fin block (about 45 x 120 x 110 mm) decided by Amish on 2026-09-25. Version 0.4 re-runs every result for the constructable design of CLR-DDR-003; only the mass, heat capacity, ramp times and cost move. Version 0.7 adds the large item case of R10 [A4] and the parts adopted on 2026-10-02; only the height, mass and cost move. Every number in this note is printed by `docs/04-calcs/sizing.py`; the tag in brackets, for example [B4], is the line of that script's output that carries it.

> **Safety:** These are first-principles estimates for a paper proof of concept. They do not replace checks of the thermal cut-offs, the fuse rating or the smoke clearance on a built rig. See CLR-PRC-001, Safety.

## Scope and method

The note checks every requirement in CLR-REQ-001 v0.9 against the design in CLR-PRC-001 v0.9 and the parametric model `cad/src/model.py`. The script imports the model's `PARAMS`, derived dimensions and part solids, so the chamber size, jacket, bay layout, footprint and mass are those of the STEP files and drawing CLR-DWG-001. It also reads `bom/bom.csv` and `budget_usd` in `project.yaml`. Run it from the repo root with `python docs/04-calcs/sizing.py`.

The design case is the reference room of CLR-REQ-001 (22 °C, 50 % RH) with the R1 room range of 15 to 30 °C, the four US EPA enhanced set points (20 °C and 40 °C at 40 % and 85 % RH), six sensor heads at the largest size in R10 and the insulated door panel fitted.

## Assumptions

*Table 1. Main assumptions.*

| Area | Assumption | Basis |
| --- | --- | --- |
| Films | Inside 10 W/(m²·K) (fan-stirred); outside 8 W/(m²·K) (still room, with radiation) | Typical values |
| Materials | Acrylic k 0.19 W/(m·K), 1,190 kg/m³, 1,470 J/(kg·K); XPS k 0.034 W/(m·K), 35 kg/m³; foam sleeve k 0.035 W/(m·K); plywood 550 kg/m³ | Handbook values |
| Thermal bridges | Edges, gasket, cable gland and fixings add 20 % to the jacketed wall conductance | Allowance |
| Air paths | Conditioning loop 3 L/min, closed from and back to the chamber, returning at room temperature; HEPA loop 20 L/min full, 5 L/min slow, H13 (99.95 %); gasket leak 0.1 air changes per hour | Design values |
| Internal gains | Mixing fan 2.4 W, inner Peltier fan 1.5 W, six heads at 0.4 W, references 0.4 W: 6.7 W [B3] | Typical fan and sensor draw; up from 4 W at TRL 2 |
| Thermoelectric module | One 12706-class module: Vmax 15.2 V, Imax 6.0 A, ΔTmax 66 K at 300 K; derived Seebeck 50.7 mV/K, resistance 1.98 Ω, conductance 0.54 W/K [A0] | Typical datasheet values, to confirm for the chosen assembly |
| Heat sinks | Outer sink with 92 mm fan 0.25 K/W; inner sink with fan 0.20 K/W (larger fin block, DDR-002; 0.45 K/W for the stock inner sink) | Typical air-to-air assembly; the 0.20 K/W figure is a target for the fin block to confirm |
| Supply | 12 V; the module voltage is limited to 12 V | Certified external supply |
| Moisture | Water diffusivity in PMMA 1 x 10⁻¹² m²/s, uptake 2 % by mass at 100 % RH, linear in RH; bubbler air leaves at 90 % saturation; silica gel holds 5 % by mass at low RH and delivers about 5 % RH air | Literature order of magnitude; to confirm |
| Aerosol | Incense smoke, deposition 0.2 per hour in a stirred chamber | Order of magnitude for sub-micron smoke |
| Reference sensors | SHT45 ±0.1 °C and ±1.0 % RH typical ([Sensirion](https://sensirion.com/products/catalog/SHT45)); a 0.2 °C tolerance is also checked because no certificate is bought; hysteresis 0.8 % RH | Datasheet typical values; the maximum figures and hysteresis are assumptions until the full datasheet is read |

## A. Geometry, capacity, size and mass (R10, R13)

The chamber is 400 x 300 x 300 mm inside (36.0 L) in a 412 x 312 x 312 mm acrylic shell [A1]. The tray is 318 x 176 mm with six 90 x 70 mm bays and 244 mm of clear height above it, so six heads at the R10 maximum of 90 x 70 x 50 mm fit, with the reference cluster behind and above them [A2].

**Large item case (CLR-DEC-001, 2026-10-02).** Two bays side by side with the 12 mm gap between them take a head up to 192 x 70 mm in plan, and a 2 x 2 block of four bays a head up to 192 x 152 mm, such as HeatMap Node's 150 mm globe. The model places each envelope at its full plan size and 234 mm tall (10 mm under the chamber top) in every position the six bays allow: four pair positions and two block positions. All 18 checks pass: each stands on the tray, stays inside the tray outline (12 mm margin) and clears the walls, the mixing fan, the inner sink and drip tray, the aerosol port and the reference cluster and mast by 5 mm or more; the closest is the chamber top, at 10 mm [A4]. A run with large heads has fewer heads: one block leaves two bays free, one pair leaves four. R10 is **met**, including the large item case.

With the chamber moved toward +X and the base trimmed, the whole rig, including the aerosol valve, the Peltier fan, the conditioning column and the salt jars, fits 600 x 500 mm and is 383 mm high, the top of the front badge being the highest point (the jacket top is at 371 mm) [A3]. Adding the bottom jacket panel raised the chamber by 25 mm, and the badge adds 12 mm, which is still within the 400 mm limit. The mass is about 13.9 kg (13.92 kg): 5.3 kg of acrylic (shell, front frame, drip tray and door), 1.5 kg of 9 mm plywood base, 0.7 kg of XPS and about 6.4 kg of bought-in and printed parts, including 0.2 kg for the larger inner fin block, 0.3 kg for the fittings, drain and printed holders added under CLR-DDR-003, and 0.1 kg for the front badge with its light and lead (0.07 kg), the pull handle (0.02 kg) and the door border (0.01 kg) adopted on 2026-10-02. R13 was relaxed from 12 kg to 14 kg under DDR-002 because CalRig is a bench rig, so R13 is **met**, with 0.08 kg of margin (0.17 kg before the 2026-10-02 parts). The 5 mm acrylic top decided as the first fallback (CLR-DDR-003, A2) would save about 0.15 kg if the finished rig weighs over 14 kg.

## B. Heat balance and temperature range (R1, R16)

With every face except the door jacketed, the wall conductance is 1.01 W/(m²·K); the clear door is 3.90 W/(m²·K) and the door with its panel 1.01 W/(m²·K) [B1]. The total chamber conductance with the panel fitted is 0.82 W/K, of which 0.06 W/K is the conditioning loop; with the panel off it is 1.17 W/K [B2]. The TRL 2 estimate of about 1.0 W/K is therefore about right, but internal gains are larger than assumed (6.7 W against 4 W) [B3].

The Peltier module is modeled with its Seebeck, Joule and conduction terms, both sink resistances and the 12 V limit, and solved for the lowest chamber temperature it can hold at full drive.

*Table 2. Lowest chamber temperature at full drive, door panel fitted [B4].*

| Room | Lowest chamber temperature | Module | Outer sink |
| --- | --- | --- | --- |
| 15 °C | -2.0 °C | 5.01 A, 12.0 V, 60 W | 35 °C |
| 22 °C | 4.1 °C | 4.98 A, 12.0 V, 60 W | 42 °C |
| 25 °C | 6.7 °C | 4.97 A, 12.0 V, 60 W | 45 °C |
| 30 °C | 11.1 °C | 4.95 A, 12.0 V, 59 W | 50 °C |

Holding 10 °C in a 25 °C room takes 19.1 W of cooling at 3.20 A, 7.8 V and 25 W, with the inner sink near 6.2 °C [B5]. Heating is easy: 40 °C in a 15 °C room needs 13.9 W at about 8 W electrical, against a heating capacity of about 80 W at 12 V [B6]. The revised R1 (10 to 40 °C in rooms of 15 to 25 °C, with the lowest point stated for warmer rooms) is therefore **met**, with a 3.3 K margin at 25 °C (1.1 K with the stock inner sink). In a 30 °C room the lowest set point is about 11 °C.

The lumped heat capacity is about 8.7 kJ/K, mostly the acrylic, and the passive time constant is 2.9 h [B7]. At full drive the chamber goes from 20 to 40 °C in about 31 min, but from 40 to 20 °C in about 78 min, and reaching 10 °C in a 25 °C room takes about 2.5 h because the margin is small [B8]. Sweeps should run from cold to hot, and 10 °C points are a separate, slower run.

The outer sink stays at or below 50 °C in normal use, 20 K under the 70 °C hot-side cut-off; the inner sink reaches about 43 °C when heating to 40 °C in a 15 °C room, and the 50 °C air cut-off is 10 K above the top set point [J2]. R16 is met.

## C. Moisture, condensation and the conditioners (R2)

Going from 20 to 85 % RH at 40 °C needs 1.19 g of water in the air and about 0.59 g taken up by the acrylic surface in 45 min, 1.8 g in all [C1]. With the loop time constant of 12 min and bubbler air at 43 °C and 90 % saturation, the chamber reaches 85 % RH in about 26 min [C2]. Drying to 20 % RH at 20 °C from room air takes about 22 min [C3]. The 500 g of silica gel holds about 25 g at low RH, enough for about 12 sweeps between regenerations [C4].

The bubbler needs two changes. A bare 500 mL jar at 43 °C loses 7.7 W in a 22 °C room, and evaporation takes another 2.7 W, which is more than the 10 W pad can give; a 10 mm foam sleeve cuts the loss to 2.4 W, and with a 0.3 L fill the pad warms the water in about 50 min, so it is preheated during the 20 °C points [C5]. Air from the bubbler also condenses in a room-temperature line: a foam-lagged 200 mm line would deliver it at about 28 °C, well below its 41 °C dew point, so the line needs a small trace heater, about 1.1 W to hold 45 °C (3 W is allowed in the BOM) [C6].

**Door condensation.** At 40 °C and 85 % RH the dew point is 37.0 °C. In a 22 °C room the clear door face runs at 33.0 °C and condenses; with the door panel it runs at 38.2 °C, a 1.2 K margin. In a 15 °C room the margin falls to 0.5 K [C7]. The door panel (adopted under DDR-001) is required, and the hot, humid point is at risk in cold rooms.

**Peltier sink condensation (R2).** At 20 °C and 85 % RH the dew point is 17.4 °C. Holding 20 °C in a 22 °C room still needs 8.3 W of cooling, mostly to remove the internal gains. With the stock 0.45 K/W inner sink of v0.1 that put the sink at about 16.2 °C, 1.2 K below the dew point: it condensed about 7.7 g/h against about 0.7 g/h from the bubbler and stayed dry only in rooms below about 19 °C, so R2 was not met [C9]. With the larger fin block decided under DDR-002 (0.20 K/W, same fan) the sink runs at about 18.3 °C, 0.9 K above the dew point, and stays dry in rooms up to about 28 °C [C8, C9]. R2 is **met** across the R1 room range of 15 to 25 °C. The 0.9 K margin is small, and the 0.20 K/W figure is a target for the chosen fin block. Cold points below the dew point will still wet the sink, so a drip tray and drain are needed in any case.

## D. Stability at a set point (R3)

A lumped plant with a PI controller, a 20 s transport delay, a 4 s sensor lag, an 8-bit drive and a room swinging ±1 K over 30 min holds the chamber within ±0.02 K [D1]. At 40 °C and 85 % RH that temperature term is worth 0.10 % RH; with an assumed ±1 % RH from the wet and dry mixing control, the humidity stability is about ±1.0 % RH [D2]. R3 is met on this idealized model, which does not include mixing inside the chamber or the sink's own lag; the chamber log planned for TRL 4 is the real check.

## E. Uniformity across the bays (R4)

The bay-to-bay temperature span is estimated as half the chamber load divided by the heat capacity rate of the mixing air, with the fan delivering 40 % of its free-air flow through the tray region. With the 80 mm fan of the TRL 2 concept the span is 0.61 K at 40 °C, 0.62 K at 20 °C and 1.42 K at 10 °C in a 25 °C room; with a 120 mm fan it falls to 0.36, 0.37 and 0.84 K [E1]. The 120 mm fan is therefore adopted in the model and BOM. That gives ±0.18 °C at the EPA set points, within the ±0.3 °C target, but ±0.42 °C at 10 °C. The humidity spread from temperature at 40 °C and 85 % RH is ±0.8 % RH [E2]. R4 is **at risk**: met at the EPA set points on a coarse estimate, not met at the cold end.

## F. Reference uncertainty (R5, R6)

*Table 3. Reference temperature uncertainty budget (standard uncertainties, °C) [F1].*

| Component | Value |
| --- | --- |
| Ice point realization (crushed ice and water) | 0.02 |
| SHT45 tolerance after the ice-point offset, 0 to 40 °C (0.1 °C, rectangular) | 0.058 |
| Drift between monthly checks (0.03 °C, rectangular) | 0.017 |
| Resolution and noise | 0.01 |
| Gradient from the reference mast to a bay (0.05 °C, rectangular) | 0.029 |
| **Expanded, k = 2** | **0.14** |

With the typical 0.1 °C tolerance the expanded uncertainty is 0.14 °C, inside the 0.2 °C target; if the tolerance is 0.2 °C, as a maximum specification would allow, it is 0.24 °C [F1]. R5 is **at risk** until a second fixed point or a certified probe pins down the slope. Under DDR-002 a certified probe is to be added if the cost target allows; the estimated cost is already above the $412 value-engineering target, so the probe is not in the BOM.

For humidity, the components are the salt fixed point itself (0.14 % RH), a 0.2 K gradient in the jar at 85 % RH (0.59), hysteresis (0.46), interpolation between fixed points (0.29) and use away from 25 °C (0.58) [F2]. The expanded uncertainty is 2.0 % RH [F3], at the 2 % RH target with no margin. R6 is **at risk**. The jar gradient and temperature terms dominate, so thermally lagged jars and fixed points taken at the chamber temperature would help most.

## G. Particles (R7, R8)

With the HEPA loop at 20 L/min, the chamber cleans from 35 to 2 µg/m³ in about 5 min, and the gasket leak holds a floor of about 0.17 µg/m³ in a 15 µg/m³ room [G1]. At 5 L/min the decay from 300 to 5 µg/m³ takes about 28 min, 29 min without deposition, so wall losses barely matter. The 300 µg/m³ start needs about 10.8 µg of smoke, which a 60 mL syringe delivers if the plume in the cup is above 0.18 mg/m³ [G2]. R7 is met. R8 is **not met** by the rig alone: the transfer SPS30 still has to be collocated. The first candidate site, a Texas Commission on Environmental Quality site in Dallas-Fort Worth, was chosen on 2026-10-02 (CLR-DEC-001).
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

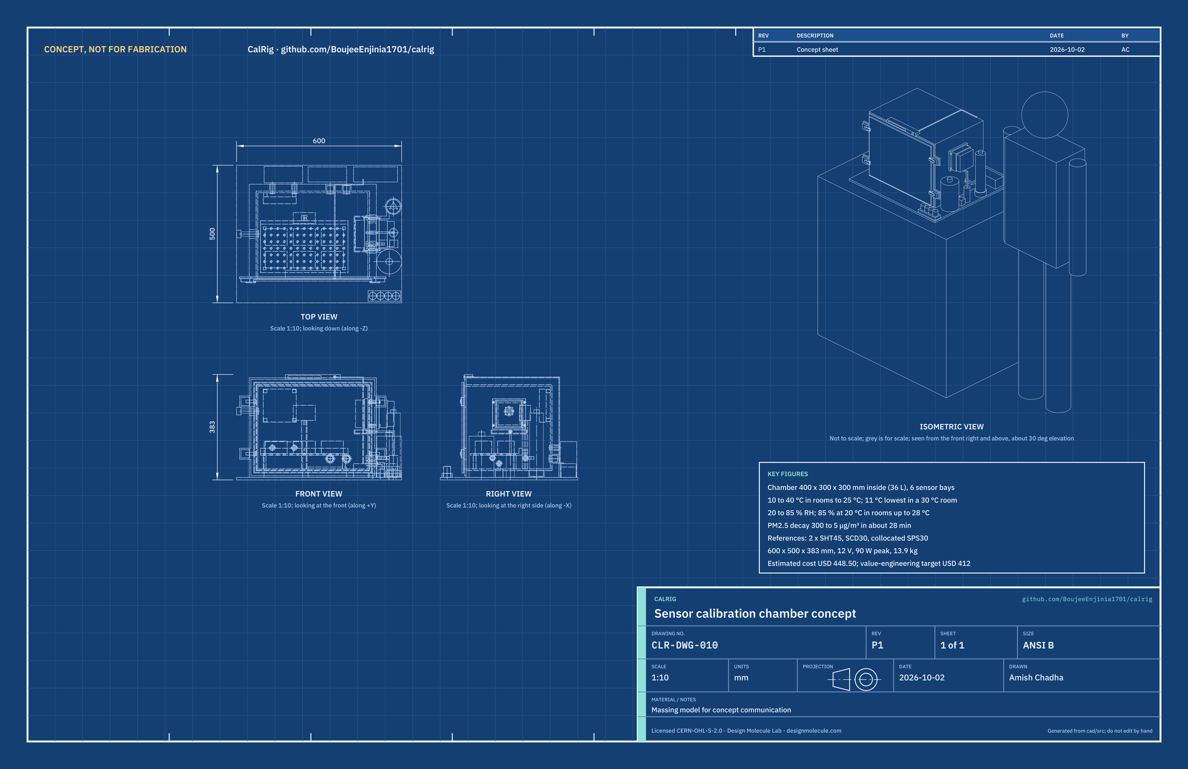
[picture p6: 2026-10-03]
media/concept-blueprint.png

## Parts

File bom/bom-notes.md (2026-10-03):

# BOM notes

- Every line in `bom.csv` carries an indicative unit price in USD and a supplier or supplier type. Prices are single-unit estimates for a garage build, not quotes.
- Value-engineering target: USD 412. Estimated cost of the constructable design: USD 448.50 on 20 lines (USD 36.50 over the target), checked by `docs/04-calcs/sizing.py` (CLR-CAL-001 v0.7 section K). The target is `budget_usd` in `project.yaml` (a hypothetical control target, not a limit; set by Amish on 2026-09-26 to cover the BOM as it then stood, CLR-DDR-002). `budget_usd` is unchanged.
- A core version without CO2 (no SCD30 in line 8 and no line 16) would be about $381.50.
- Change after CLR-DDR-002: line 5 now includes a larger inner fin block (about 0.20 K/W, about $8), so the 20 °C, 85 % RH point holds in rooms up to about 28 °C. A certified temperature probe (decided if the cost target allows) is not included, because the estimate is already above the $412 value-engineering target.
- Changes at TRL 3: line 3 now jackets every face except the door and includes the removable door panel; line 4 is trimmed to 600 x 500 mm; line 6 is a 120 mm fan; line 9 adds a foam sleeve and a trace-heated outlet line. Line numbers 1 to 15 match the exploded view and drawing CLR-DWG-001.
- Line 18 (software) is priced at zero and is not written at TRL 3.
- Changes for construction (CLR-DDR-003, 2026-10-01): line 1 adds the front frame, drip tray and fan spacers; line 2 has a 430 x 330 mm door and four latches; line 3 a smaller door panel on hook-and-loop pads; line 4 is 9 mm plywood with six feet (mass); line 5 adds clamp screws and sleeves; line 10 a printed socket; line 13 a cut-off relay (no price change); line 15 a printed rack; new line 19 holds the bulkhead fittings, cable glands and drain. Line numbers 1 to 15 and 19 match the exploded view.
- Decisions of 2026-10-02 (CLR-DEC-001): the base stays 9 mm sealed birch plywood (line 4). The front status light and name plate, the printed door border and the door panel pull handle are adopted in the design; they were added to `bom.csv` and the model the same day (below).
- Approved follow-ups of 2026-10-02 (`docs/REVIEW.md`): line 2 adds the 22 mm printed vinyl door border ($17 to $20; about $3 for a cut vinyl frame from a sign or print shop); line 3 adds the printed PETG pull handle on the door panel ($17 to $18; about 25 g of PETG); line 13 names the status light output (spare pin and switch, no price change); new line 20, front badge, status light and name plate ($5.50: printed badge about $1, 12 V panel indicator light about $1.50, name plate label about $1.50, lead, plug and clips about $1.50). Mass added about 0.1 kg (CLR-CAL-001 [A3]). Line numbers 1 to 15, 19 and 20 match the exploded view.

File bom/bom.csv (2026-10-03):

item | qty | spec | supplier | unit_cost_usd | make_buy | notes
1 Chamber shell | 1 | 6 mm cast acrylic, five-sided box 412 x 312 x 312 mm outside (400 x 300 x 300 mm inside, 36 L), solvent-welded; front frame 450 x 350 mm with four latch tabs, drip tray and four fan spacers welded on; 90 x 100 mm Peltier opening and every port, gland, drain and clamp hole laser cut | Plastics supplier or maker space laser cutter | 51.00 | make | Indicative price for about 0.8 m2 of 6 mm cast sheet and cutting; frame, drip tray and spacers added for construction (CLR-DDR-003); per CLR-DWG-102 and 103
2 Front door | 1 | 6 mm clear acrylic door 430 x 330 mm with a 22 mm matt black printed vinyl border on its front face (cut round the keepers), silicone D-section gasket on the front frame, four draw latches with keepers | Plastics supplier and hardware store | 20.00 | make | Indicative price; four latches instead of two and a larger door so the gasket seats on the frame; cable gland moved to line 19 (CLR-DDR-003). Printed border added 2026-10-02 (CLR-DEC-001): about $3 for a cut vinyl frame 430 x 330 mm from a sign or print shop
3 Insulation jacket | 1 | 25 mm XPS foam on bottom, top, back, left and right (Peltier, port, gland, drain and clamp-sleeve holes), plus a removable 25 mm door panel 406 x 330 mm on four hook-and-loop pads with a printed PETG pull handle glued to its front, foam-safe adhesive and foil tape | Building supplier | 18.00 | make | Indicative price; one 1.2 x 1.2 m sheet; all faces jacketed after CLR-CAL-001 section B; hook-and-loop pads added (CLR-DDR-003). Pull handle added 2026-10-02 (CLR-DEC-001): about $1, roughly 25 g of PETG at about $25/kg plus printing
4 Base plate | 1 | 9 mm birch plywood, 600 x 500 mm, sealed, six stick-on rubber feet | Hardware store | 10.00 | make | Indicative price; 9 mm instead of 12 mm keeps the rig under the 14 kg limit of R13 after the construction changes (CLR-DDR-003)
5 Peltier heat pump | 1 | 12 V air-to-air thermoelectric assembly, about 60 W input, outer finned sink and 92 mm fan; inner sink replaced by a larger fin block (about 45 x 120 x 110 mm, about 0.20 K/W with its fan); four M4 stainless clamp screws with rigid sleeves through the jacket, thermal paste | Electronics distributor | 40.00 | buy | Indicative price: $30 assembly, about $8 for the larger inner fin block (CLR-DDR-002) and $2 for longer clamp screws and sleeves (CLR-DDR-003); a second module is an option if R1 cooling is required in warm rooms
6 Internal mixing fan | 1 | 120 mm 12 V fan, about 85 m3/h free air, PWM speed control, guarded | Electronics distributor | 6.00 | buy | Indicative price; 120 mm replaces 80 mm for bay uniformity (CLR-CAL-001 section E)
7 Sensor tray | 1 | Perforated aluminium or acrylic tray with six bays, cable rail, USB and I2C hub | Maker space and electronics distributor | 12.00 | make | Indicative price
8 Reference cluster | 1 | 2 x Sensirion SHT45 breakout (about $12.50 each), Sensirion SCD30 CO2 (about $59), Sensirion SPS30 PM transfer sensor (about $48), printed mast | Electronics distributor | 132.00 | buy | Indicative price; SPS30 must be collocated at a monitor before use (R8)
9 Humidifier bubbler | 1 | 500 mL glass jar filled to 300 mL, air stone, 10 W 12 V heater pad with thermistor, 10 mm foam sleeve, 12 V diaphragm air pump about 3 L/min, 200 mm outlet line with a 3 W resistance-wire trace under foam, distilled water | Aquarium and electronics supplier | 15.00 | buy | Indicative price; sleeve and trace heat added after CLR-CAL-001 section C
10 Dryer column | 1 | 50 mm acrylic tube about 230 mm long, 500 g indicating silica gel, 12 V diaphragm air pump, printed socket screwed to the base | Laboratory and electronics supplier | 17.00 | buy | Indicative price; socket added for construction (CLR-DDR-003)
11 HEPA scrubber loop | 1 | H13 class filter cartridge, 60 mm blower, variable speed, silicone tubing | HVAC and electronics supplier | 15.00 | buy | Indicative price
12 Aerosol injection port | 1 | Female Luer bulkhead port, small ball valve, 60 mL syringe, metal incense cup | Laboratory supplier | 6.00 | buy | Indicative price
13 Controller and power board | 1 | ESP32 class board, 15 A H-bridge for the Peltier, MOSFETs for fans, pumps and heater, a switched output for the front status light, microSD, independent bimetal thermal cut-offs (50 C air, 70 C hot side) holding in a cut-off relay on the Peltier and heater supply, 10 A blade fuse | Electronics distributor | 25.00 | buy | Indicative price; the status light output uses a spare controller pin and switch (2026-10-02), no price change
14 Power supply | 1 | Certified external 12 V 10 A (120 W) supply with regional mains lead | Electronics distributor | 20.00 | buy | Indicative price; no mains wiring inside the rig
15 Salt fixed-point jars | 1 | Four sealed jars with LiCl, MgCl2, NaCl and KCl saturated slurries (analytical grade), sensor lid adapters, printed rack screwed to the base | Laboratory supplier | 19.00 | buy | Indicative price; fixed points per Greenspan (1977); rack added for construction (CLR-DDR-003)
16 Soda lime cartridge | 1 | Small inline cartridge with about 100 g indicating soda lime for CO2 zero | Laboratory supplier | 8.00 | buy | Indicative price; not modelled; optional with CO2 checks
17 Wiring and consumables | 1 | Wire, connectors, silicone tubing, sealant, fasteners, labels, heat-shrink | Hardware store | 15.00 | buy | Indicative price; not modelled
18 Control and fitting software | 1 | Controller sketch and laptop fitting script writing CSV and per-sensor reports, MIT license | Design Molecule | 0.00 | make | Not modelled; written at TRL 3 or later
19 Bulkhead fittings, glands and drain | 1 | Five 12 mm barbed bulkhead fittings with nuts and O-rings (three on the right wall, two to the HEPA unit), one 6 mm barbed drain bulkhead, two M20 cable glands with multi-hole seal inserts, 250 mL drain bottle with lid, 6 mm drain tube | Plumbing, laboratory and electronics supplier | 14.00 | buy | Indicative price; added for construction: the air loops, drain and leads had no way through the wall (CLR-DDR-003)
20 Front badge, status light and name plate | 1 | Printed PETG front badge 200 x 30 mm with a lip to the front frame, glued to the top jacket panel; 12 V panel indicator light, 5 mm, in an 8 mm bezel with built-in resistor; name plate label 120 x 10 mm; two-core 0.25 mm2 lead about 0.9 m with a plug for the controller, stuck-on cable clips | Maker space, electronics distributor and print shop | 5.50 | make | Indicative price (added 2026-10-02, CLR-DEC-001): badge about $1 (about 45 g of PETG), panel indicator light about $1.50, name plate label about $1.50, lead, plug and clips about $1.50

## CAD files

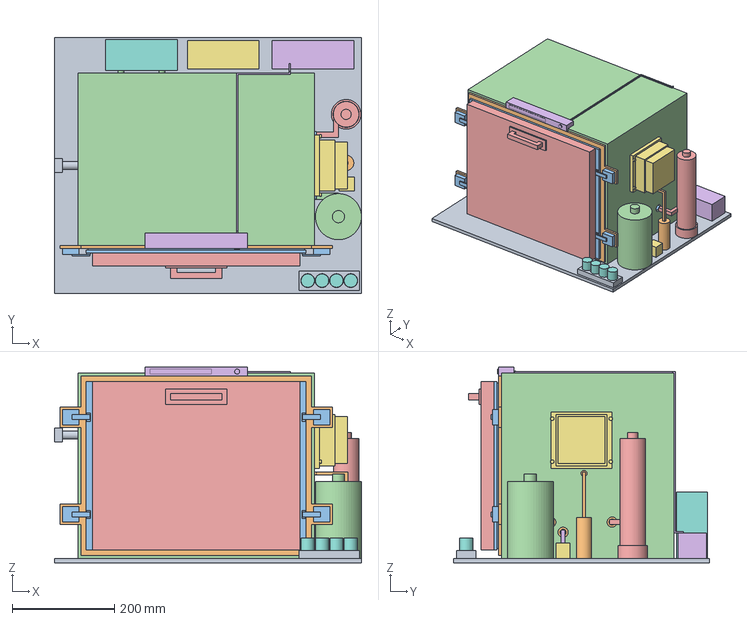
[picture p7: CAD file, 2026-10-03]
cad/step/calrig-assembly.step
600.0 x 500.0 x 383.0 mm

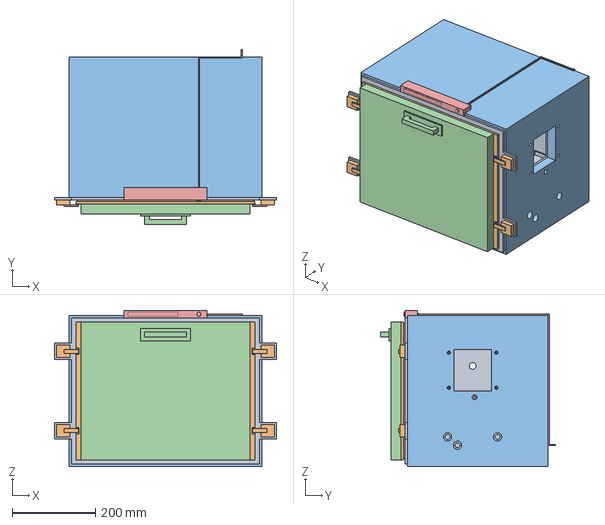
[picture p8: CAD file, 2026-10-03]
cad/step/chamber.step
532.0 x 420.0 x 374.0 mm

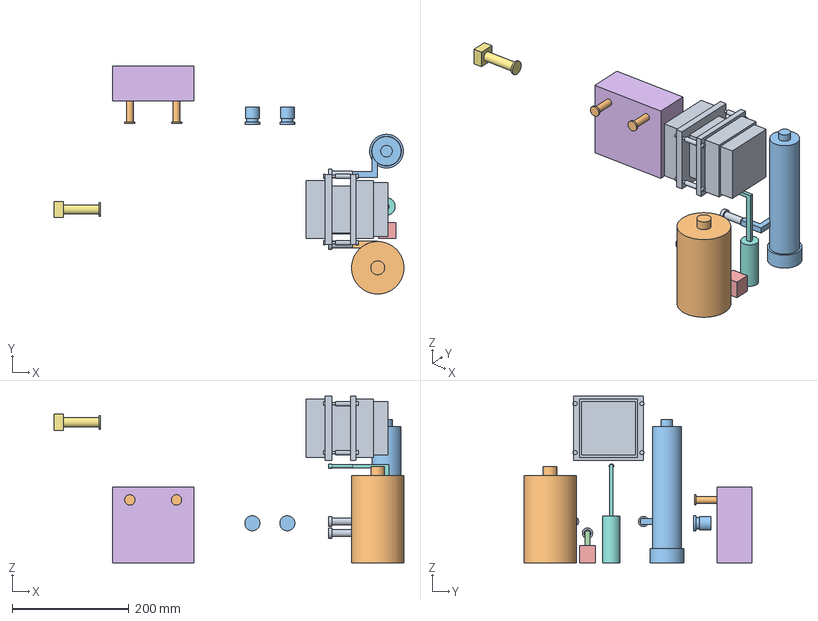
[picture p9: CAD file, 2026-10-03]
cad/step/conditioning.step
600.0 x 391.0 x 286.0 mm

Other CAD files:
cad/stl/calrig-assembly.stl
cad/stl/chamber.stl
cad/stl/conditioning.stl

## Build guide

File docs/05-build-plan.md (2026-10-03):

---
doc_id: CLR-BLD-001
title: CalRig prototype build plan
project: CalRig
doc_type: Build plan
version: "0.2"
status: Draft
date: '2026-10-02'
author: Amish Chadha
license: CERN-OHL-S-2.0
revisions:
  - version: "0.1"
    date: '2026-10-01'
    author: Amish Chadha
    change: First build plan, with pictures by component and step; design made constructable (CLR-DDR-003)
  - version: "0.2"
    date: '2026-10-02'
    author: Amish Chadha
    change: Decisions of 2026-10-02 carried into the plan (front badge with name plate and status light and its wiring, printed door border, door panel pull handle, large heads in the first checks); new section 3.15, Figures 23 and 24 and step 12; figures and steps renumbered
---

# CalRig prototype build plan

**Plan, not yet built.** How to build the first proof-of-concept prototype, component by component. Building and testing to it is TRL 4 work. Decisions still to be made are kept in the design decisions register ([docs/06-design-decisions.md](06-design-decisions.md)), not here.

## 1. What you are building

Figure 1. Every component, pulled apart and numbered in build order

*Figure 1. Every component pulled apart and numbered in build order, seen from the front right and above.*

The prototype is one CalRig on a bench: a 36 L clear acrylic box wrapped in foam board, with a door at the front, a heat pump through its right wall, and the conditioning parts, the HEPA unit and the electronics standing on a plywood base around it. Figure 1 shows the 26 components in the order you make or fit them. Eleven are made in a workshop or maker space: the base plate, the five jacket panels, the chamber shell with its welded front frame, drip tray and fan spacers, the sensor tray, the door with its printed border and the door panel from sheet, and four small printed parts (the reference mast, the dryer socket, the jar rack and the front badge), with a printed pull handle on the door panel. The rest are bought and fitted: the heat pump, fans, pumps, bubbler, dryer column, HEPA unit, bulkhead fittings and cable glands, latches, sensors, the front status light and its lead, controller and power supply. The work is laser cutting and solvent welding acrylic, cutting foam board, a little drilling and printing, and wiring bought modules together with screw terminals. The parts cost about $449, from the bill of materials.

> **Safety:** The rig runs from a certified external 12 V supply; no mains wiring is inside it. The heat pump's outer sink reaches 50 °C and its hot side can reach 70 °C; the heaters and heat pump are cut off by two bimetal switches whatever the software does. Test smoke contains fine particles and some carbon monoxide: light the incense outside the chamber in a ventilated room and clear the chamber through the HEPA unit before opening the door. Soda lime is corrosive and lithium chloride is harmful if swallowed: wear gloves and eye protection. Acrylic solvent cement and laser-cut acrylic give off fumes: work in a ventilated space.

## 2. What changed to make it buildable

The concept showed what the rig does; some of its parts could not be made or fixed as drawn. Each change below keeps what the rig does. The construction changes are recorded in decision record CLR-DDR-003, accepted by Amish on 2026-10-02; the last three rows are details adopted on the same day (design decisions register).

*Table 1. Changes from the concept.*

| Component | The concept had | The buildable design has | Why |
| --- | --- | --- | --- |
| Door | A door the size of the shell, sealing on the 6 mm wall edges; two latches with nothing to catch | A welded front frame with a 25 mm gasket face, a 430 x 330 mm door and four draw latches on frame tabs (Figures 5 and 27) | The gasket needs a face to seal on and the latches something to pull against |
| Door panel | A full-front foam panel standing loose in front of the latches | A 406 x 330 mm panel on the door, between the latches, on four hook-and-loop pads (Figure 22) | Held in place and off by hand |
| Heat pump | No clamping to the wall | Both sink bases clamp the wall with four screws through rigid sleeves in the foam (Figure 14) | Standard mounting for a through-wall heat pump |
| Mixing fan | Floating off the back wall | Four welded spacers, fan 15 mm off the wall (Figure 15) | No hole through the wall |
| Sensor tray and reference mast | Thin posts; the mast floated behind the tray | 10 mm legs; a printed mast standing on the floor against the tray's rail (Figure 18) | Both stand on the floor and come out through the door |
| Air loops | Lines ending at the foam with no way through the wall; no outlet for the pumps; the HEPA unit not connected | Five 12 mm bulkhead fittings (wet inlet, dry inlet, suction, two to the HEPA unit) and two pumps on the base (Figures 11 to 13 and 25) | A closed loop needs a way out of the chamber as well as in |
| Sensor leads | One gland in the door | Two cable glands in the back wall (Figure 13) | Leads stay put when the door opens |
| Drip tray and drain | Named in the concept but not drawn | A tray under the inner sink, a drain fitting and a bottle on the base (Figure 9) | Condensate at cold points leaves the chamber |
| Base plate | 12 mm plywood or HDPE | 9 mm sealed birch plywood | Keeps the rig under the 14 kg limit after the added parts (13.9 kg) |
| Status light and name plate | Not drawn | A printed badge on the front of the jacket's top panel, its lip resting on the front frame, carrying the name plate and a 12 V panel light wired to the controller (Figures 23 and 24) | Shows that a run is going without opening the rig; the badge adds 12 mm to the height (383 mm) |
| Door border | Not drawn | A 22 mm black printed border on the door's front face, cut round the keepers (Figure 21) | Hides the frame edges and gasket |
| Door panel handle | Nothing to pull it off by | A printed pull handle glued to the panel's front (Figure 22) | The panel comes off for every warm, dry point |

## 3. Making the components

Make and check each component before the assembly step that needs it. Sizes are in millimetres. "Left" and "right" are as seen standing at the front of the rig, looking at the door. Workshop tolerance is 0.5 mm unless a step says otherwise; drawings do not carry tolerances before TRL 4.

### 3.1 Base plate

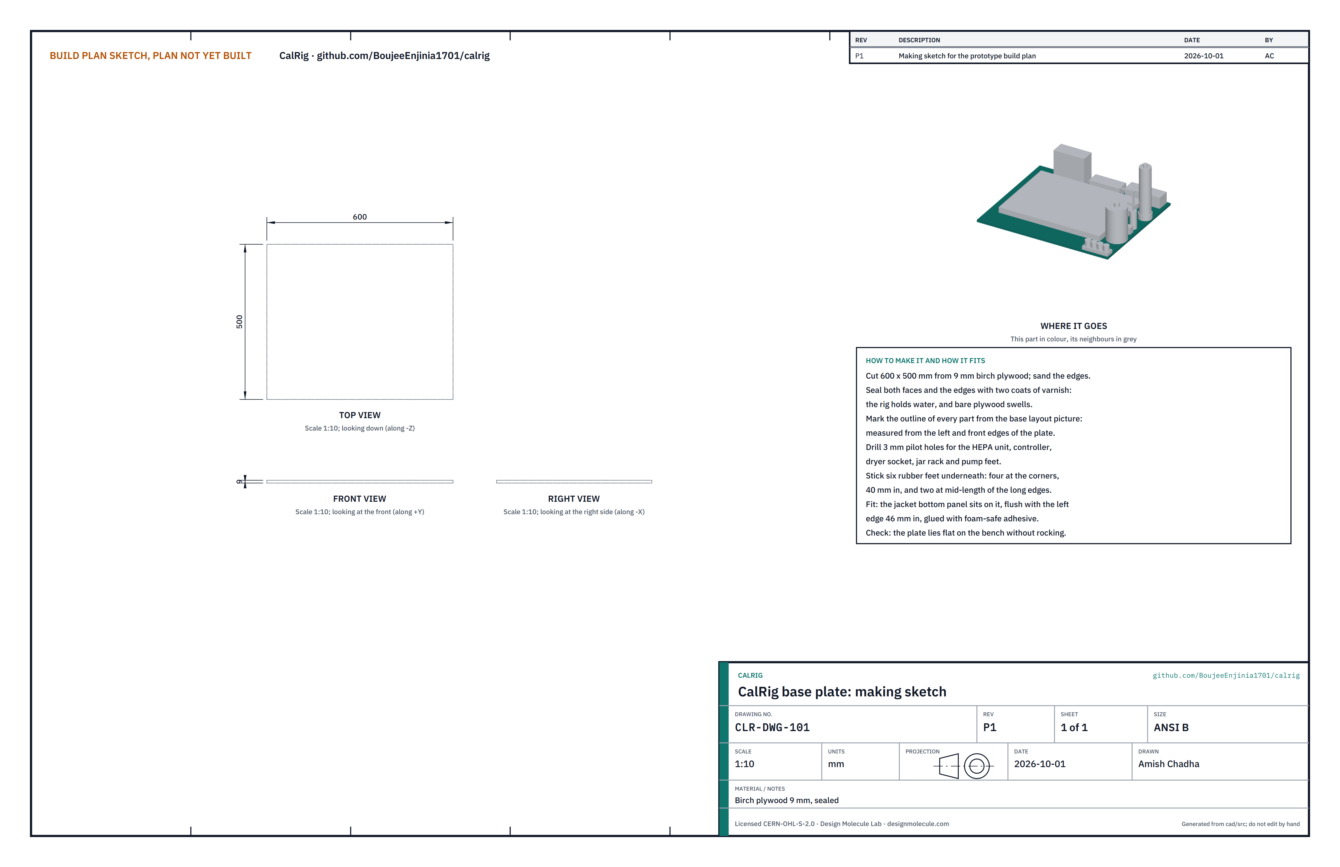
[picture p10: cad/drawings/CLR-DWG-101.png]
Figure 2. Making sketch of the base plate


*Figure 2. Base plate making sketch (CLR-DWG-101).*

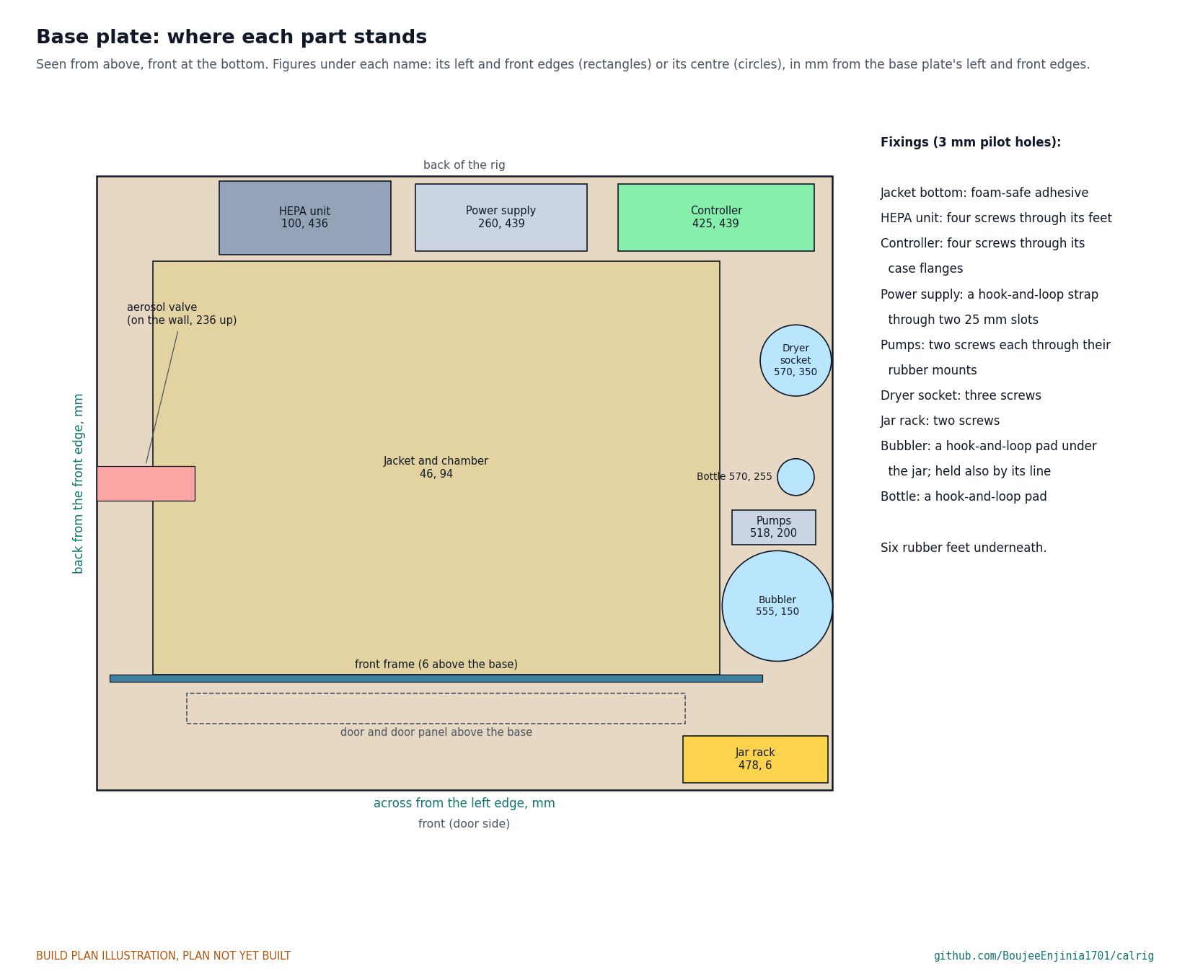
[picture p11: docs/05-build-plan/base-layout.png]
Figure 3. Where each part stands on the base plate


*Figure 3. Where each part stands, measured from the base plate's left and front edges.*

**What it is and what it is made from.** The board everything stands on. Birch plywood 9 mm thick, cut to 600 x 500 mm.

**How to make it.**

1. Cut the blank to 600 x 500 mm, square, and sand the edges.
2. Seal both faces and all edges with two coats of varnish. The rig holds water, and bare plywood swells.
3. Mark the outline of every part from Figure 3, measured from the left and front edges.
4. Drill 3 mm pilot holes for the screws of the HEPA unit, controller, pumps, dryer socket and jar rack, through the marked feet or flanges of each part.
5. Cut two 25 mm slots for the power supply's strap, either side of its outline.
6. Stick six rubber feet underneath: four at the corners, 40 mm in, and two at mid-length of the long edges.

**How it fits the parts next to it.** The jacket's bottom panel is glued flat on it, 46 mm from the left edge and 94 mm from the front edge. Everything else stands on it and is screwed, strapped or padded down as Figure 3 lists.

**Check before moving on.** The plate lies flat on the bench without rocking.

### 3.2 Insulation jacket

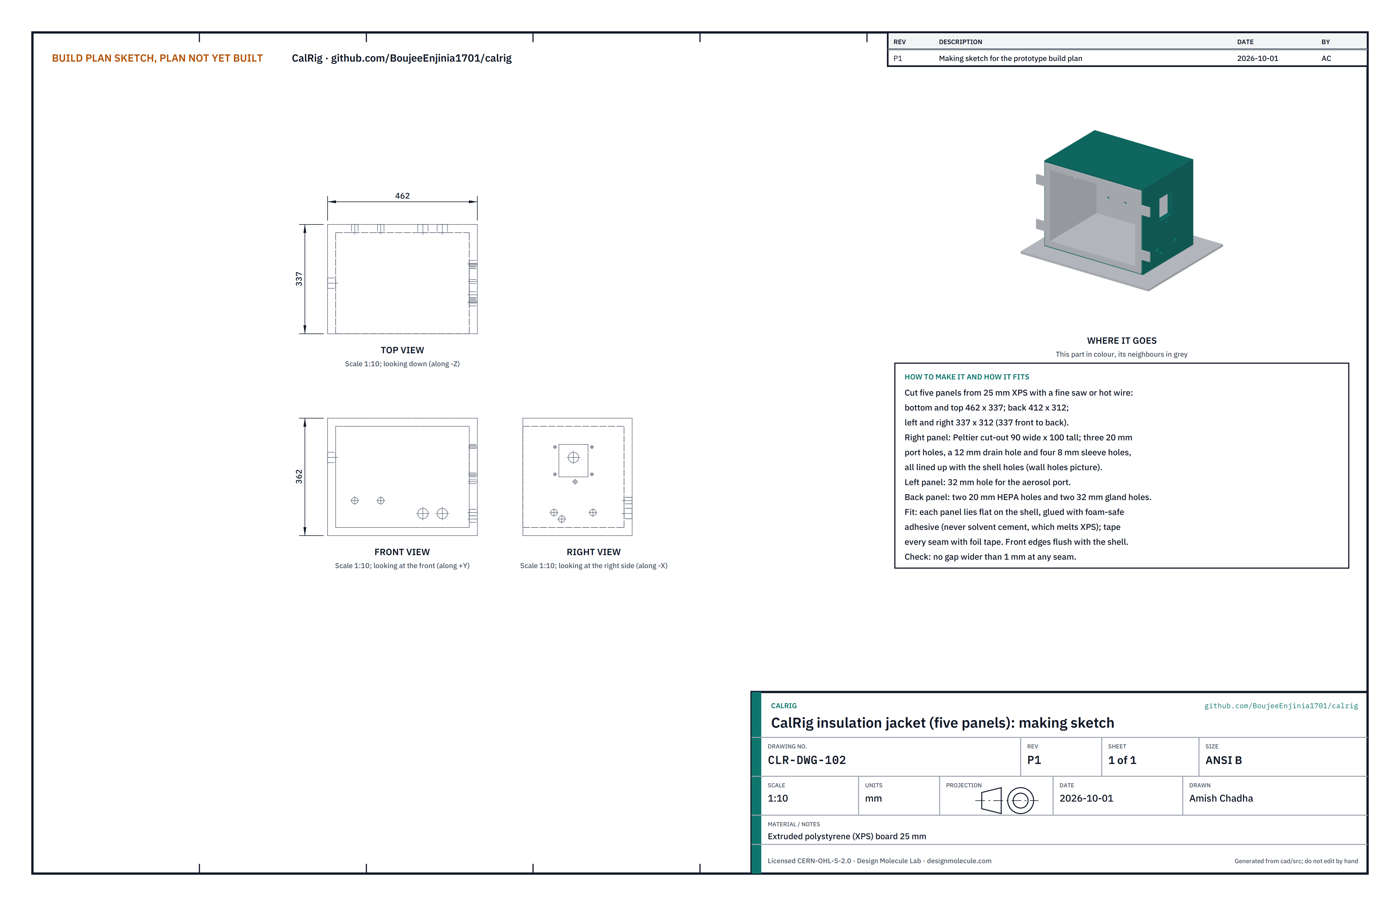
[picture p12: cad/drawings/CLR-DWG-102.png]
Figure 4. Making sketch of the jacket panels


*Figure 4. Insulation jacket making sketch (CLR-DWG-102). The hole positions are in Figure 6.*

**What it is and what it is made from.** Five panels of 25 mm extruded polystyrene board that wrap the shell on every face but the front. One 1.2 x 1.2 m sheet is enough.

**How to make it.**

1. Cut the bottom and top panels 462 x 337 mm, the back panel 412 x 312 mm, and the left and right panels 337 mm front to back by 312 mm tall. A fine-toothed saw or a hot wire gives a clean edge.
2. Right panel: cut the heat pump opening 90 wide by 100 tall, three 20 mm holes for the air fittings, a 12 mm hole for the drain and four 8 mm holes for the clamp sleeves, at the positions of Figure 6 plus 6 mm up (the side panels sit on the bottom panel).
3. Left panel: a 32 mm hole for the aerosol port.
4. Back panel: two 20 mm holes for the HEPA fittings and two 32 mm holes for the cable glands, at the positions of Figure 6 plus 6 mm along and 6 mm up.
5. Hold each panel against the shell (section 3.3) to check that every hole lines up before gluing anything.

**How it fits the parts next to it.** The bottom panel is glued to the base; the shell sits on it; the other four panels lie flat against the shell, glued with foam-safe adhesive (never acrylic solvent cement, which melts the foam). Every seam is taped with foil tape. The front edges are flush with the front of the shell, and the front frame covers the inner 19 mm of them (Figure 5).

**Check before moving on.** No gap wider than 1 mm at any seam; every hole is clear of the fitting that passes through it.

### 3.3 Chamber shell, with its fan spacers

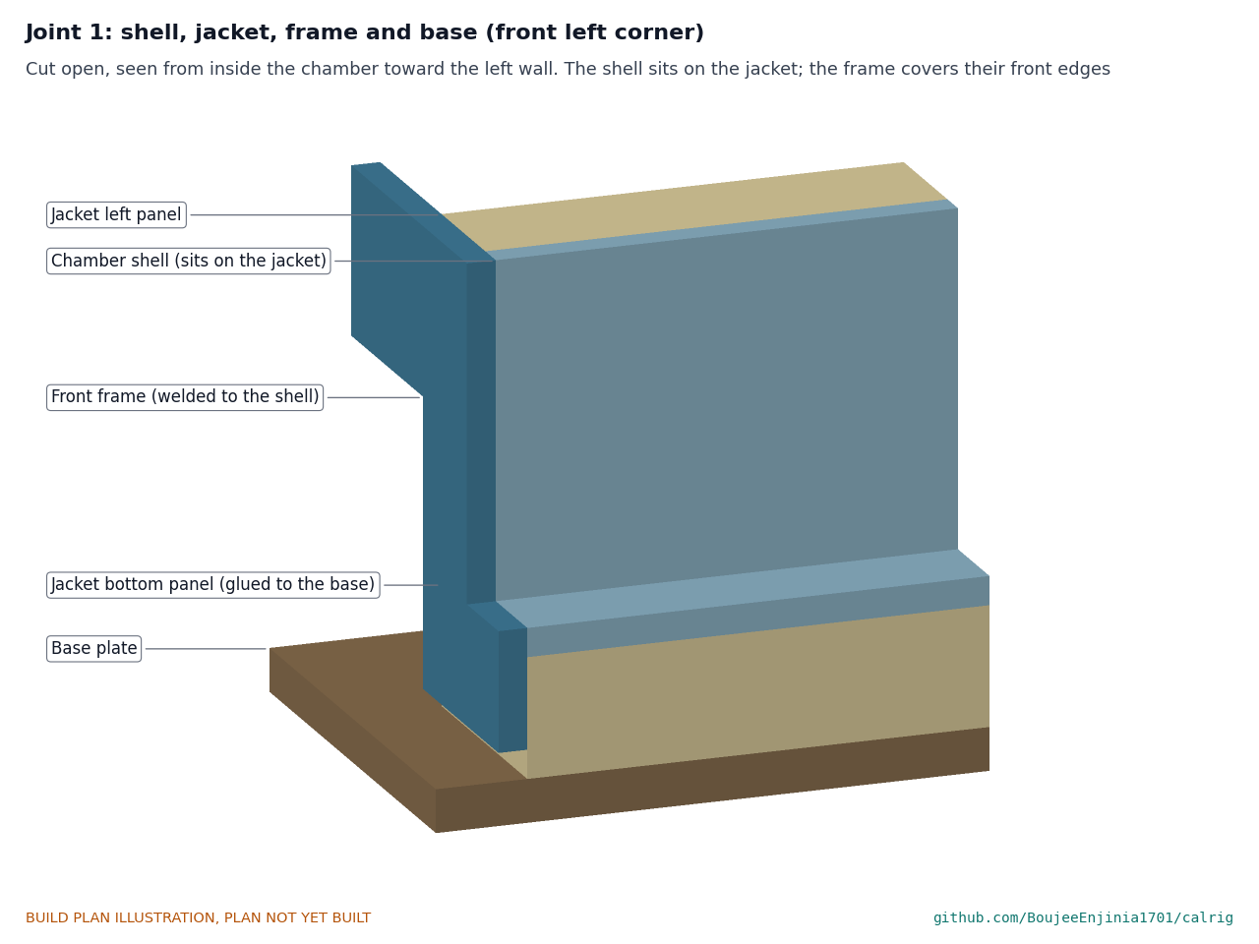
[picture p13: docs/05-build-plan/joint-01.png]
Figure 5. Joint 1: shell, jacket, frame and base


*Figure 5. The front left corner cut open: the shell sits on the jacket's bottom panel, which is glued to the base; the front frame is welded to the shell and covers the jacket's front edges.*

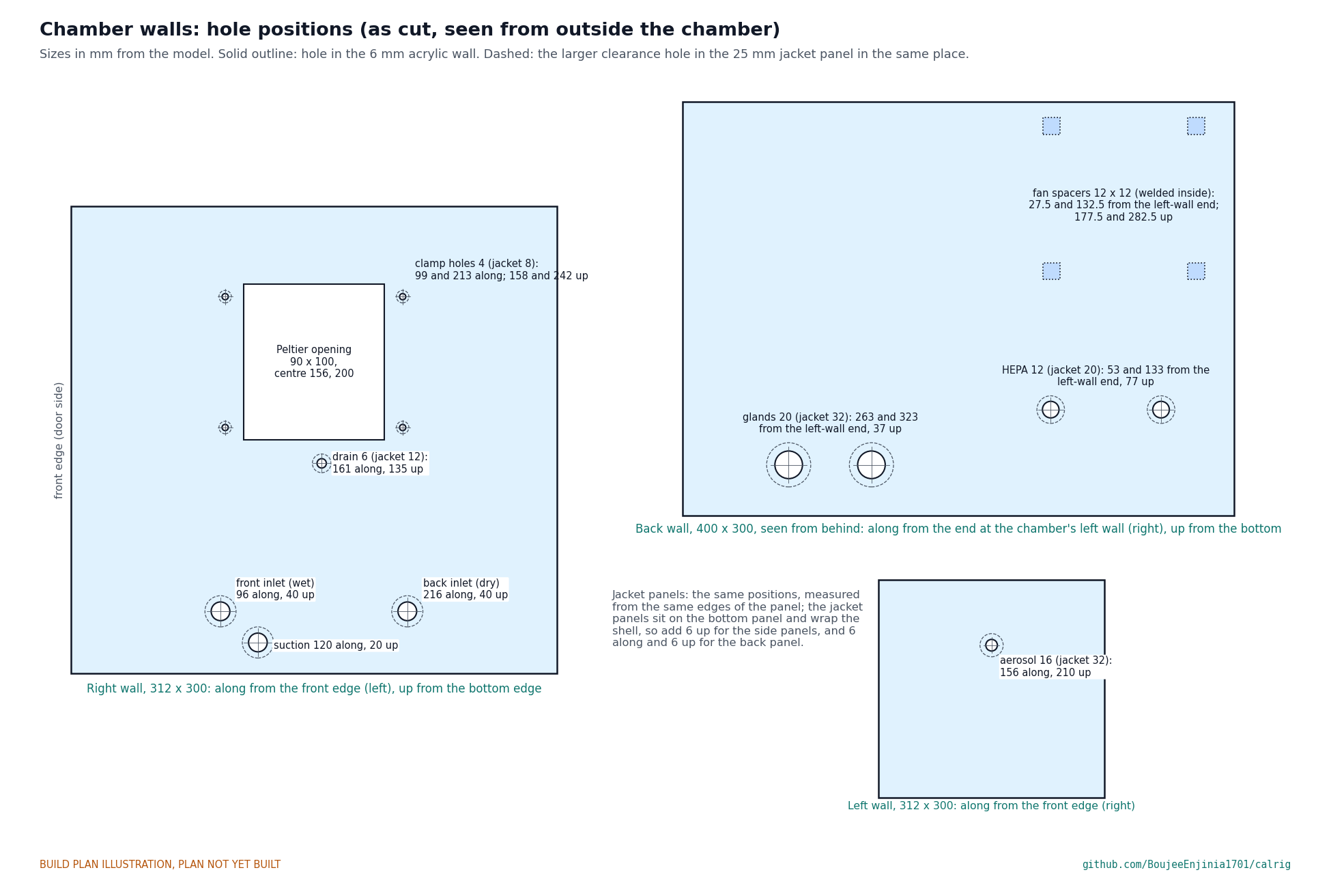
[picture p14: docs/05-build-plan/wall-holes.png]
Figure 6. Hole positions in the chamber walls


*Figure 6. Hole positions in the right, back and left walls as cut, seen from outside, with the larger jacket holes dashed.*

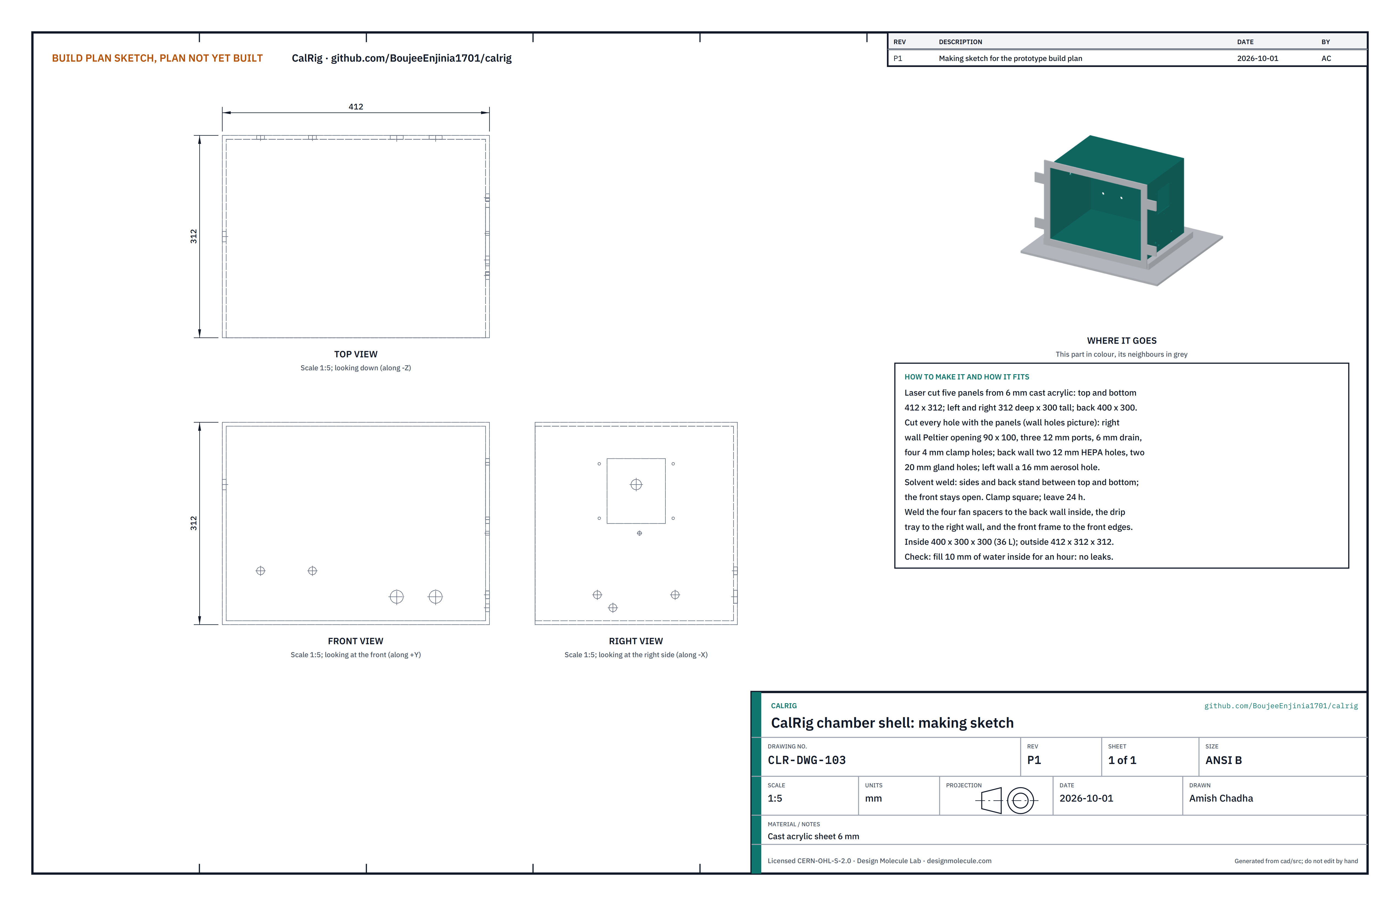
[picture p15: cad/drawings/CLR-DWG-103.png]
Figure 7. Making sketch of the chamber shell


*Figure 7. Chamber shell making sketch (CLR-DWG-103).*

**What it is and what it is made from.** The sealed five-sided box the sensors sit in, 400 x 300 x 300 mm inside (36 L), open at the front. Cast acrylic sheet 6 mm thick; cast, not extruded, because it welds and machines without crazing.

**How to make it.**

1. Laser cut five panels: top and bottom 412 x 312 mm; left and right 312 mm deep by 300 mm tall; back 400 x 300 mm.
2. Cut every hole with its panel, at the positions of Figure 6. Right wall: the heat pump opening 90 wide by 100 tall, centred 156 from the front edge and 200 up; three 12 mm holes for the wet inlet, dry inlet and suction; a 6 mm drain hole; four 4 mm clamp holes. Back wall: two 12 mm holes for the HEPA fittings and two 20 mm holes for the cable glands. Left wall: a 16 mm hole for the aerosol port.
3. Cut four fan spacers 12 x 12 x 15 mm from offcut and drill and tap each M4 down its length.
4. Solvent weld the box: the sides and the back stand on the bottom panel, between the sides, and the top sits on them. The front stays open. Clamp it square with corner blocks and leave it 24 hours.
5. Weld the four spacers to the inside of the back wall at the positions of Figure 6.
6. Weld the drip tray (section 3.5) and the front frame (section 3.4) when they are made.

**How it fits the parts next to it.** The bottom sits flat on the jacket's bottom panel, glued with foam-safe adhesive (Figure 5). Every fitting seals on the acrylic with an O-ring outside and a nut inside; the jacket holes are clear of them.

**Check before moving on.** Stand the box on its back and pour in 10 mm of water: after an hour there is no leak at any weld. Dry it fully.

### 3.4 Front frame

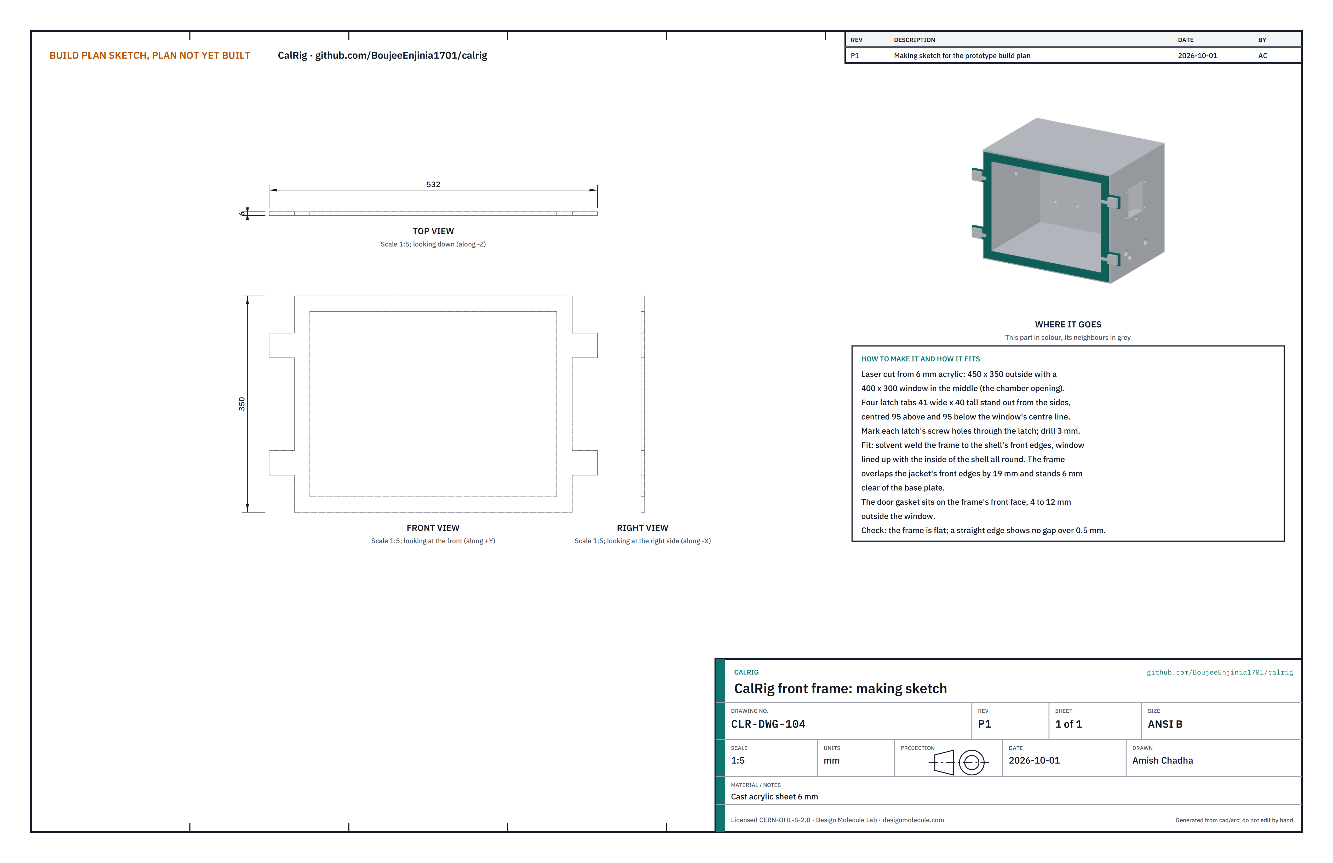
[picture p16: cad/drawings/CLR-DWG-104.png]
Figure 8. Making sketch of the front frame


*Figure 8. Front frame making sketch (CLR-DWG-104).*

**What it is and what it is made from.** A flat frame welded to the front of the shell, which gives the door gasket a face to seal on and carries the four latches. Cast acrylic sheet 6 mm.

**How to make it.**

1. Laser cut a 450 x 350 mm frame with a 400 x 300 mm window in the middle.
2. Include four tabs 41 wide by 40 tall standing out from the sides, centred 95 above and 95 below the window's centre line.
3. Hold a latch on each tab, mark its screw holes and drill 3 mm.

**How it fits the parts next to it.** Solvent weld it to the shell's front edges with the window lined up with the inside of the shell all round. It overlaps the jacket's front edges by 19 mm (Figure 5) and stands 6 mm clear of the base plate. The gasket goes on its front face, 4 to 12 mm outside the window (Figure 27).

**Check before moving on.** A straight edge across the frame shows no gap over 0.5 mm.

### 3.5 Drip tray

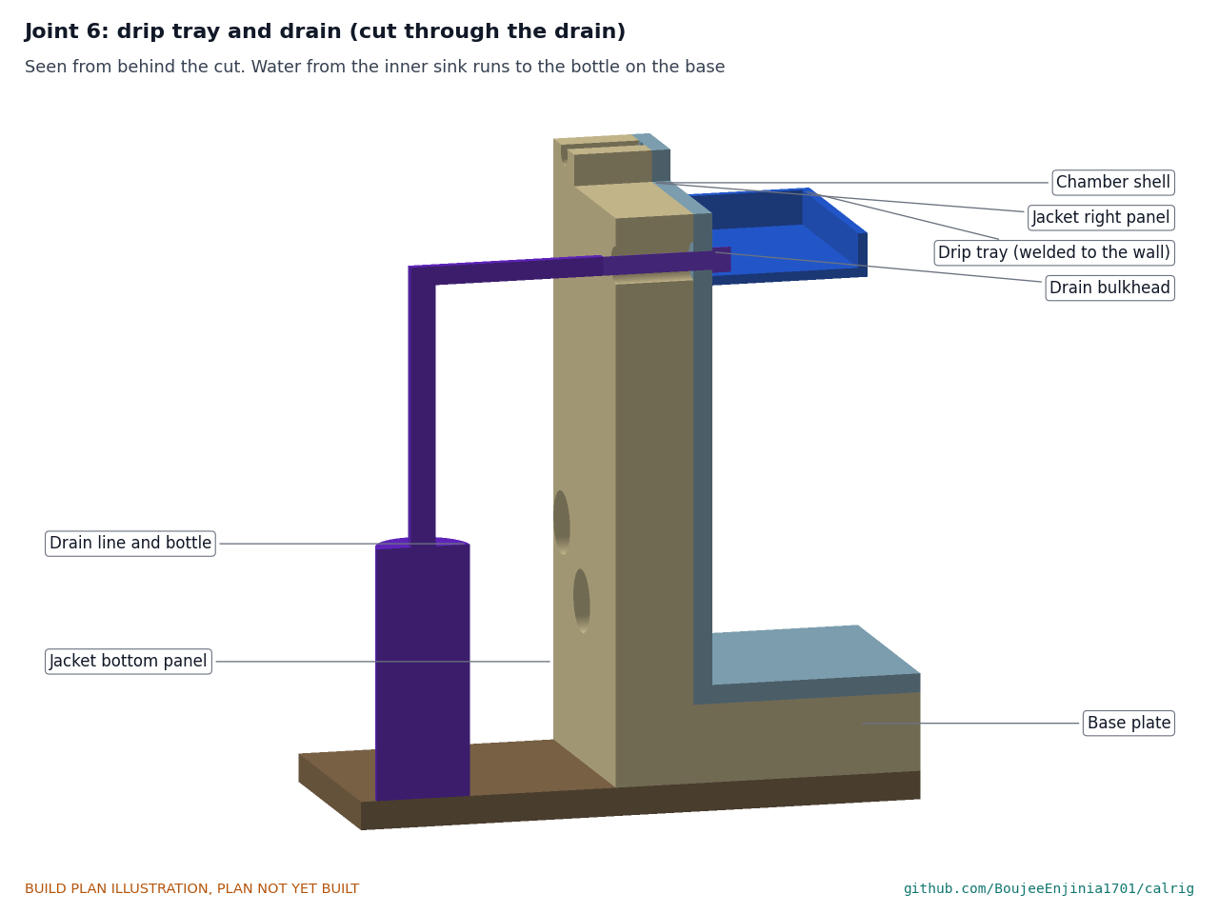
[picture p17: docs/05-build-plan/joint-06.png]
Figure 9. Joint 6: drip tray and drain


*Figure 9. Cut through the drain: water from the inner sink collects in the tray and runs through the wall to the bottle on the base.*

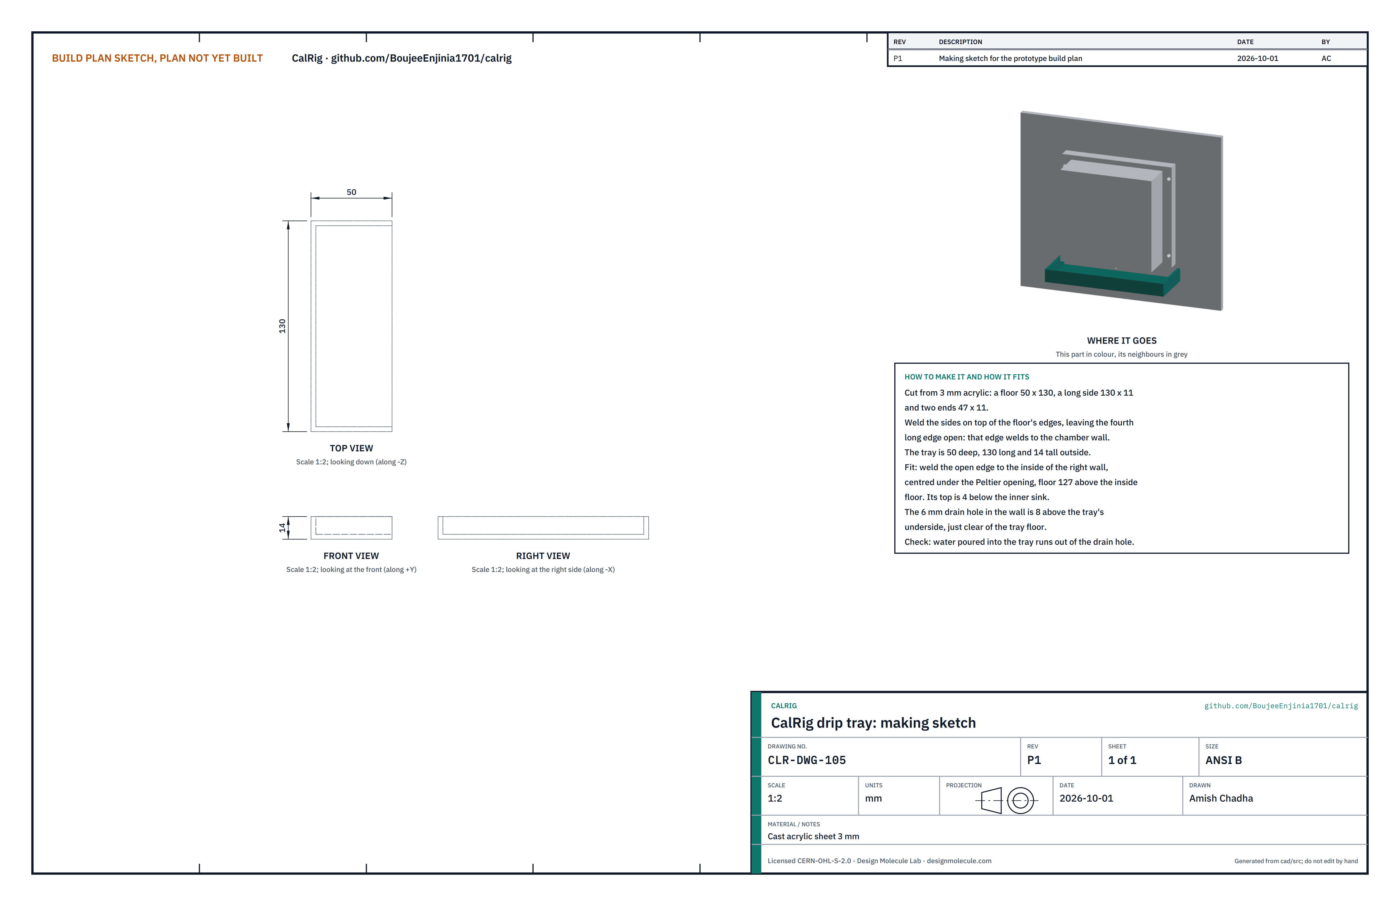
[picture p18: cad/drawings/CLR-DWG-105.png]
Figure 10. Making sketch of the drip tray


*Figure 10. Drip tray making sketch (CLR-DWG-105).*

**What it is and what it is made from.** A shallow open tray under the heat pump's inner sink that catches condensate at cold, humid set points. Cast acrylic sheet 3 mm.

**How to make it.**

1. Cut a floor 50 x 130 mm, one long side 130 x 11 mm and two ends 47 x 11 mm.
2. Weld the side and ends on top of the floor's edges, leaving the fourth long edge open. The tray is 50 deep, 130 long and 14 tall outside.

**How it fits the parts next to it.** Weld its open edge to the inside of the right wall, centred under the heat pump opening, with its floor 127 above the inside floor. Its top is 4 mm below the inner sink. The 6 mm drain hole in the wall is 8 mm above the tray's underside, just clear of the tray floor.

**Check before moving on.** Water poured into the tray runs out of the drain hole.

### 3.6 Bulkhead fittings, cable glands and aerosol port

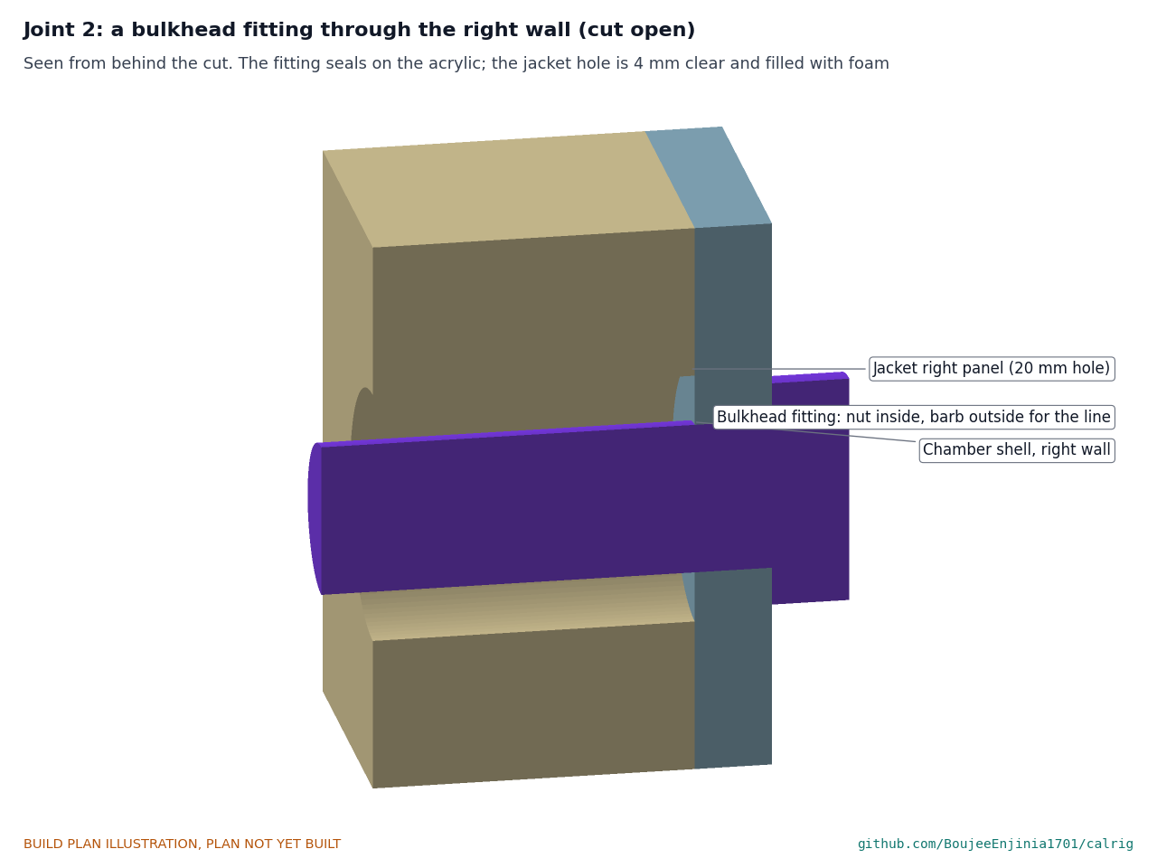
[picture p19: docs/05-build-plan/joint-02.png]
Figure 11. Joint 2: a bulkhead fitting through the right wall


*Figure 11. A bulkhead fitting cut open: it seals on the acrylic with an O-ring outside and a nut inside; the jacket hole is 4 mm clear and is filled with foam after fitting.*

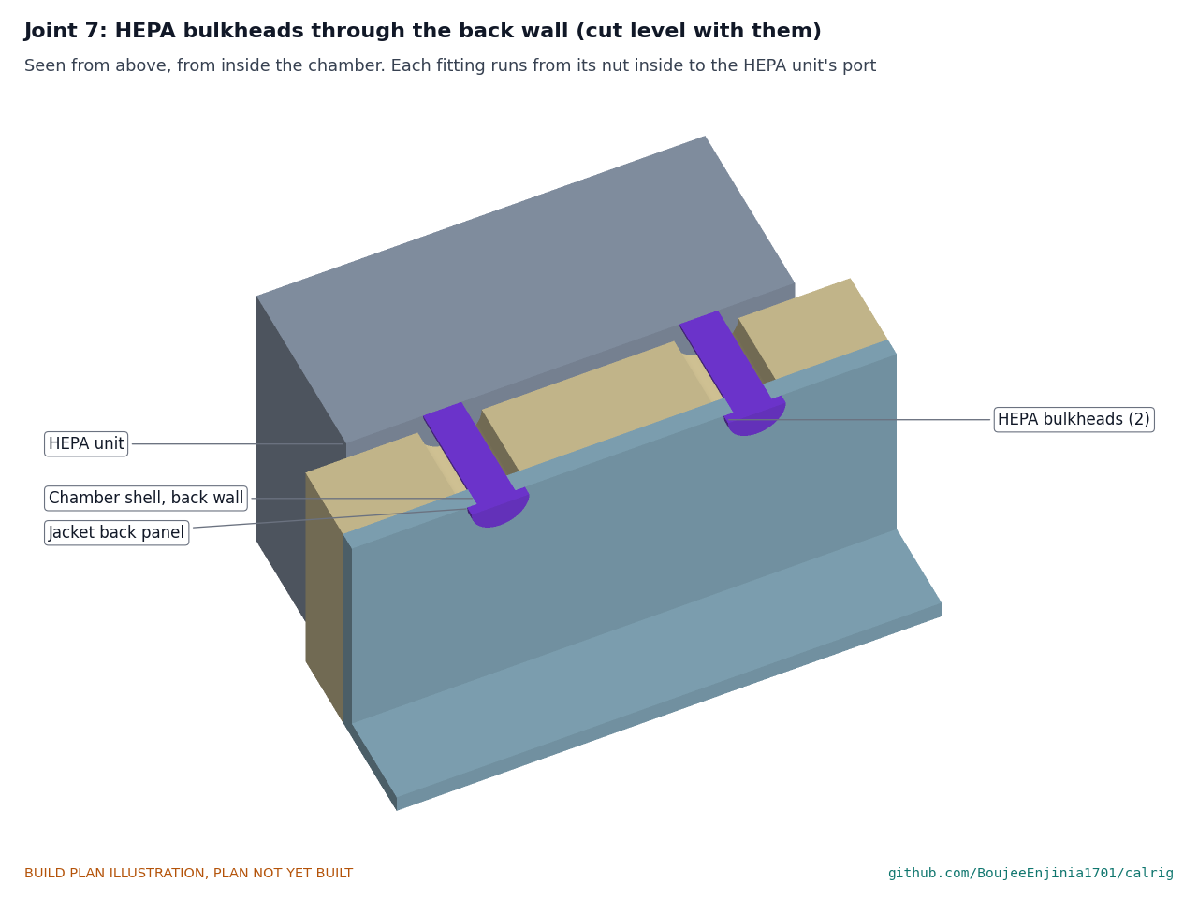
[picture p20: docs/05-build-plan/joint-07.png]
Figure 12. Joint 7: HEPA fittings through the back wall


*Figure 12. The two HEPA fittings run straight from their nuts inside to the HEPA unit's ports.*

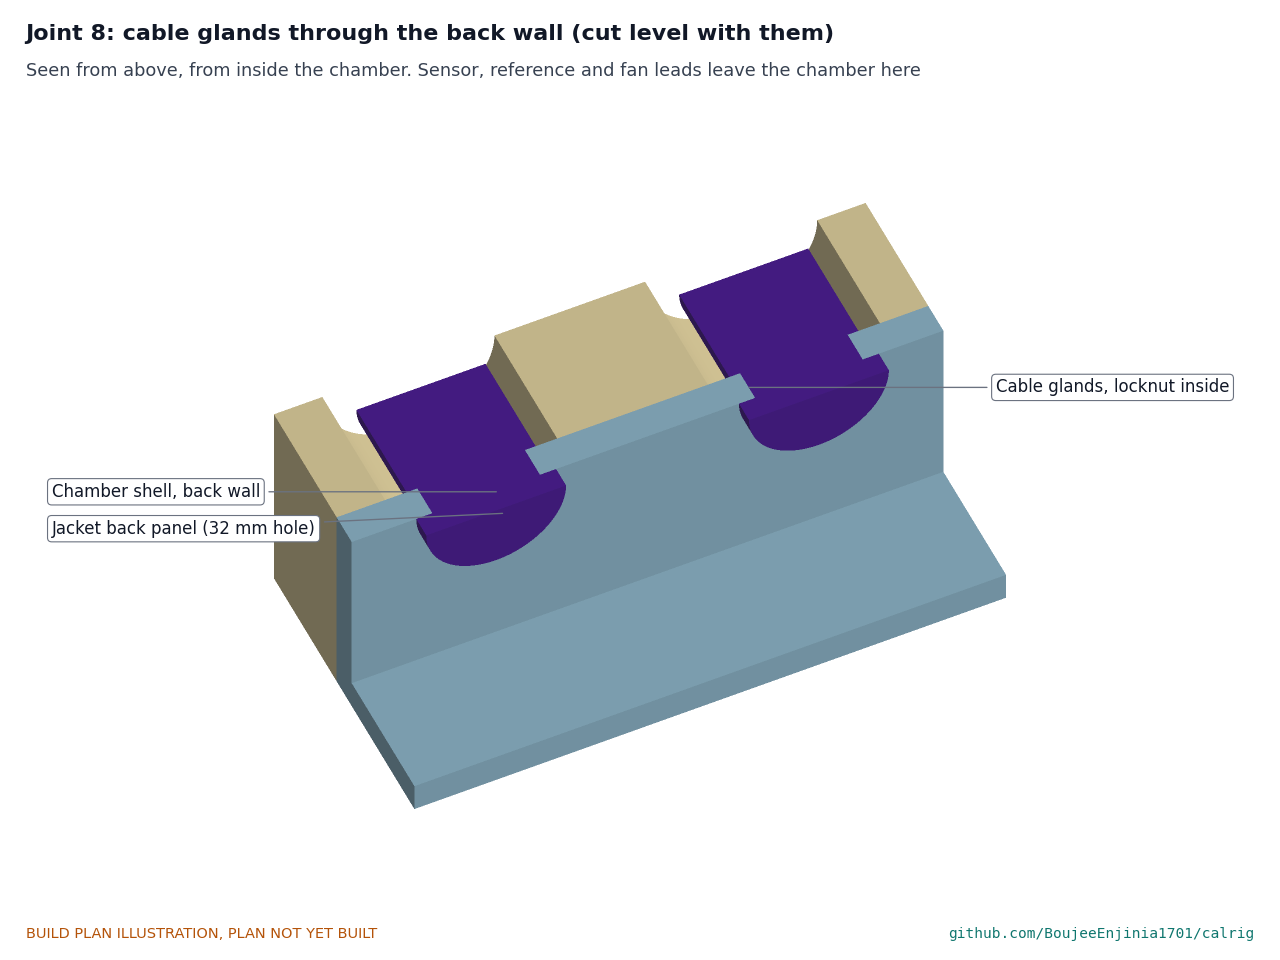
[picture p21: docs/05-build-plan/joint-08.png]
Figure 13. Joint 8: cable glands through the back wall


*Figure 13. The two cable glands, with their locknuts inside the chamber.*

**What they are.** Bought fittings that take air, water and leads through the sealed walls: three 12 mm barbed bulkheads in the right wall (wet inlet at the front, dry inlet at the back, suction low between them), two 12 mm barbed bulkheads in the back wall to the HEPA unit, one 6 mm barbed bulkhead for the drain, two M20 cable glands with multi-hole seal inserts in the back wall, and the aerosol port: a 16 mm bulkhead with a Luer fitting and a small ball valve.

**What to do to them.** Nothing but fit them (step 3): each goes in from outside with its O-ring on the outside face, and its nut is tightened from inside through the open front. Check each one's thread size against the 12, 6, 20 and 16 mm holes before cutting the shell. After the jacket is on, fill the clearance round each fitting with a foam offcut and seal the surface with tape.

**Check before moving on.** Each fitting sits square and does not turn by hand once tight.

### 3.7 Peltier heat pump

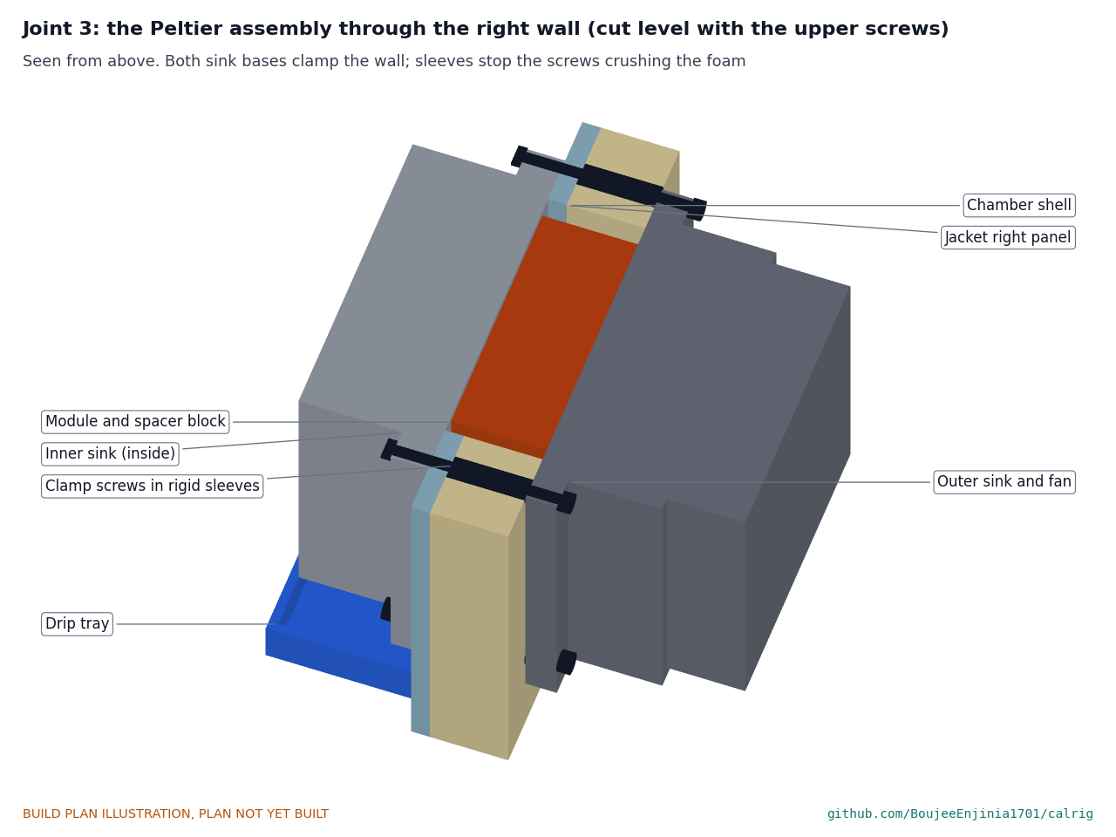
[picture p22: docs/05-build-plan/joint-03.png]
Figure 14. Joint 3: the heat pump through the right wall


*Figure 14. Cut level with the upper clamp screws: the inner and outer sink bases clamp the wall between them, the module and spacer block sit in the opening, and rigid sleeves carry the screws through the foam.*

**What it is.** A bought 12 V air-to-air thermoelectric assembly of about 60 W, with its stock inner sink replaced by a larger fin block (about 45 x 120 x 110 mm) and fan. Both sink bases must be at least 120 x 110 mm.

**What to do to it.**

1. Drill four 4.2 mm clamp holes through each sink base, 57 mm either side of the centre and 42 mm above and below it, matching the shell's clamp holes.
2. Cut four rigid sleeves 25 mm long from 8 mm outside, 4 mm bore plastic tube.
3. Spread a thin layer of thermal paste on both faces of the module.

**How it fits the parts next to it.** The inner sink's base sits flat on the inside of the right wall over the opening, with a thin foam gasket; the outer sink's base sits flat on the jacket over the same opening. The 80 x 80 mm module and spacer block sits between them in the 90 x 100 mm opening, 5 mm clear all round; fill that gap with foam offcuts and sealant. Four M4 stainless screws pass through both bases, the wall and the sleeves; tighten them evenly in a cross pattern so the module is squeezed flat.

**Check before moving on.** Both sinks sit flat; the module cannot be moved; nothing touches the acrylic but the inner sink's base and its gasket.

### 3.8 Mixing fan

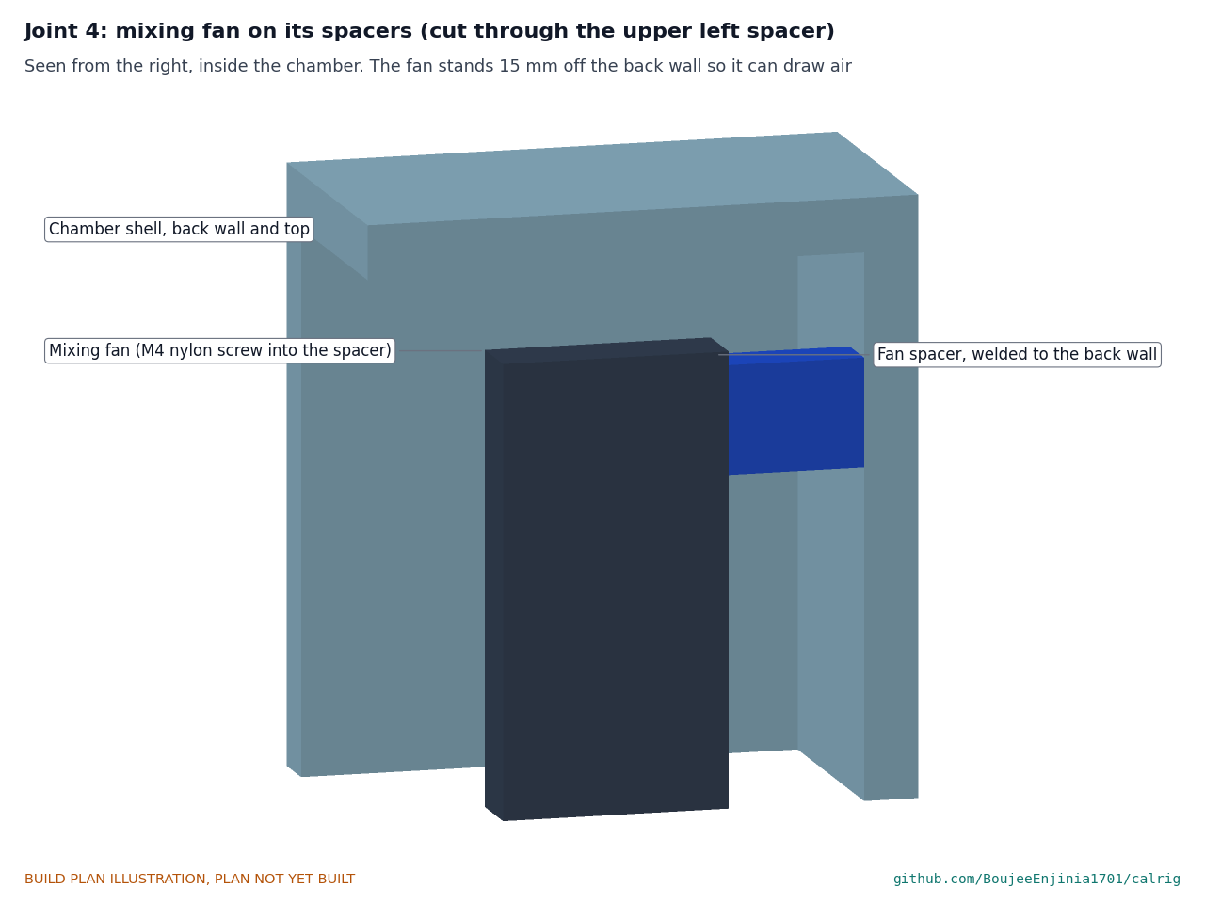
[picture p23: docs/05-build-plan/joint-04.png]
Figure 15. Joint 4: mixing fan on its spacers


*Figure 15. Cut through the upper left spacer: the fan stands 15 mm off the back wall on its welded spacers.*

**What it is.** A bought 120 mm, 12 V fan with speed control and a finger guard.

**How it fits the parts next to it.** It screws to the four spacers on the back wall with four M4 nylon screws, blowing toward the door, 10 mm below the top and 20 mm from the left wall. Its lead runs down the back wall to a cable gland.

**Check before moving on.** The blades turn freely by hand and clear the guard.

### 3.9 Sensor tray

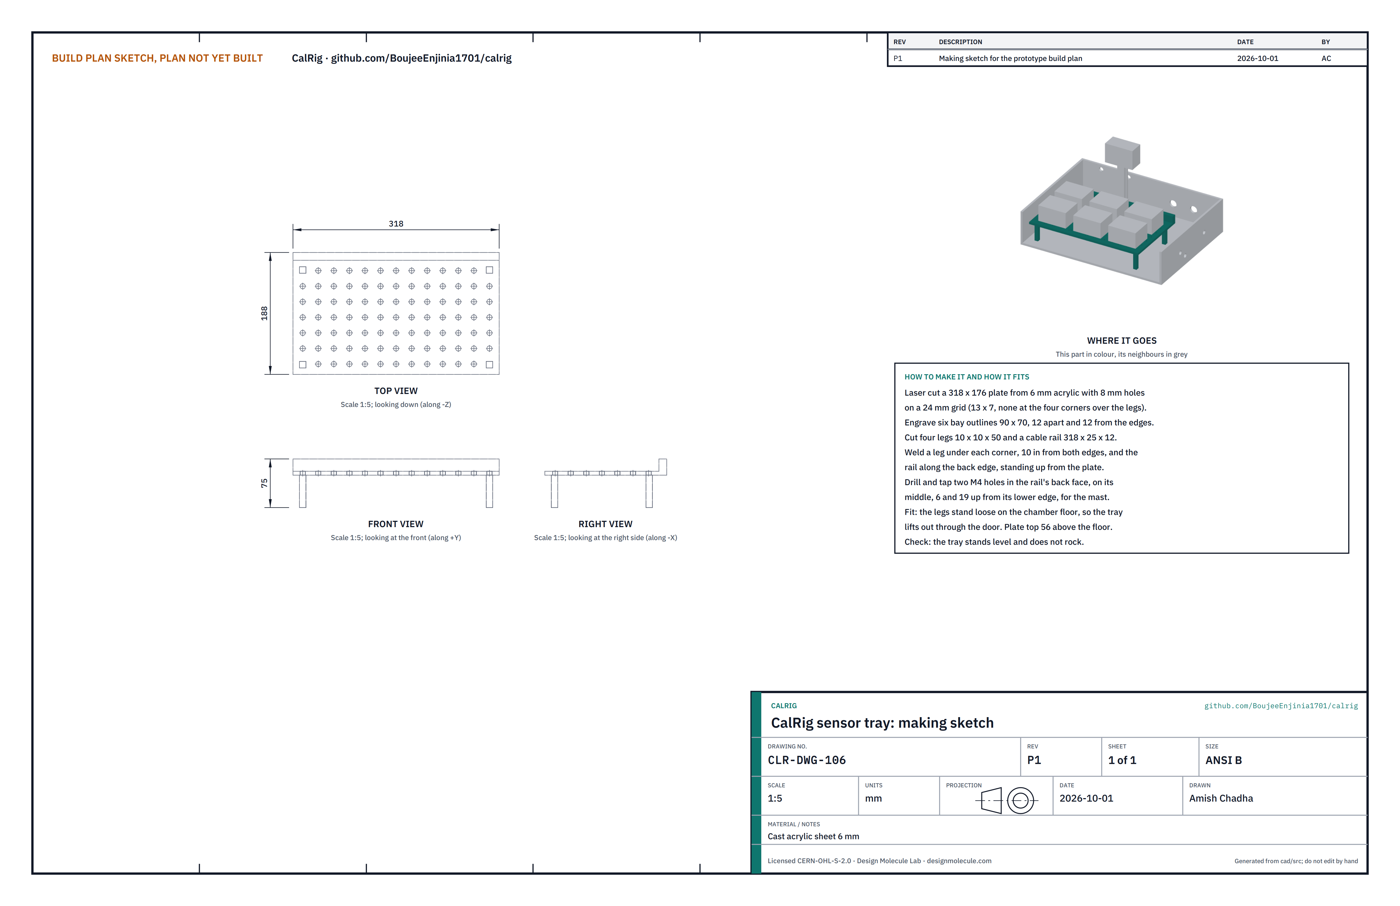
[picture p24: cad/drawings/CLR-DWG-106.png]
Figure 16. Making sketch of the sensor tray


*Figure 16. Sensor tray making sketch (CLR-DWG-106).*

**What it is and what it is made from.** The perforated shelf that holds six sensor heads at the largest size the rig takes (90 x 70 x 50 mm), with a cable rail along its back. Cast acrylic sheet 6 mm.

**How to make it.**

1. Laser cut a 318 x 176 mm plate with 8 mm holes on a 24 mm grid (13 by 7), leaving out the four corner holes. Engrave six bay outlines 90 x 70 mm, 12 mm apart and 12 mm from the edges.
2. Cut four legs 10 x 10 x 50 mm and a rail 318 x 25 x 12 mm.
3. Weld a leg under each corner, 10 mm in from both edges, and the rail along the back edge, standing up from the plate.
4. Drill and tap two M4 holes in the rail's back face, on its middle, 6 and 19 mm up from its lower edge.

**How it fits the parts next to it.** The legs stand loose on the chamber floor, 10 mm from the left wall and 16 mm behind the front opening; the plate top is 56 mm above the floor and the tray lifts out through the door. Nothing on it touches the drip tray or the inner sink.

**Check before moving on.** The tray stands level and does not rock.

### 3.10 Reference mast and cluster

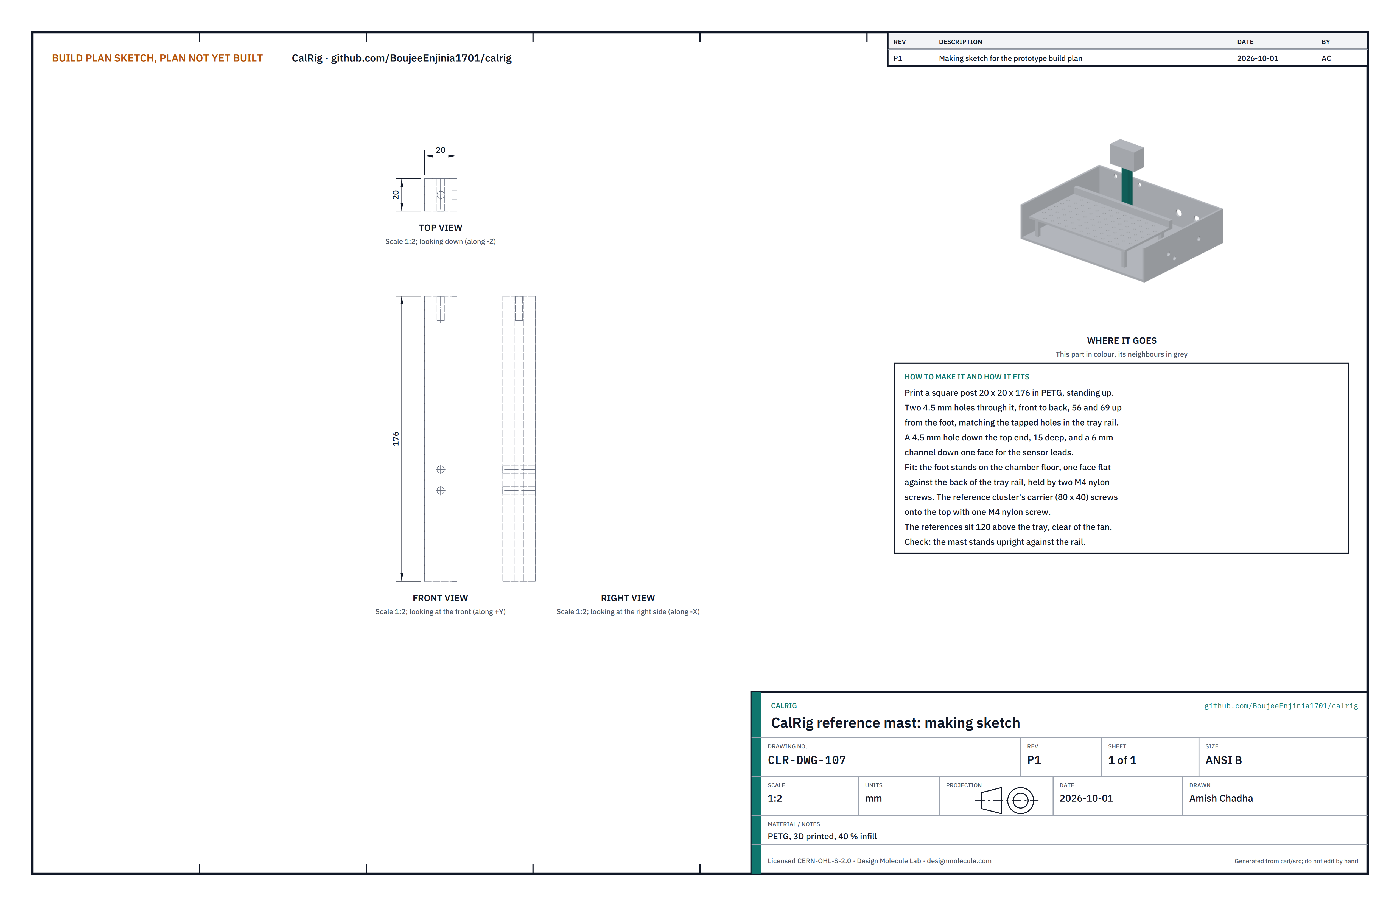
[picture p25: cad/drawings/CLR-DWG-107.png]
Figure 17. Making sketch of the reference mast


*Figure 17. Reference mast making sketch (CLR-DWG-107).*

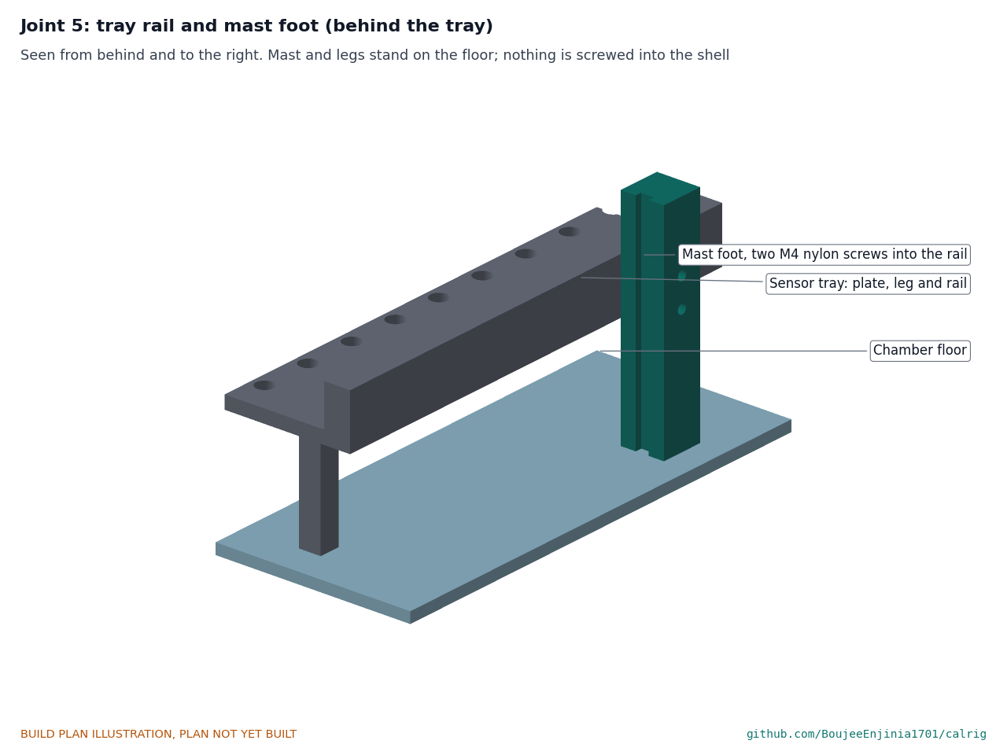
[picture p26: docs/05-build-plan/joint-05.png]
Figure 18. Joint 5: tray rail and mast foot


*Figure 18. The mast stands on the floor against the back of the tray rail; the tray's legs stand on the floor too, so nothing is screwed into the shell.*

**What it is and what it is made from.** A square post that holds the reference cluster (two SHT45 temperature and humidity sensors, an SCD30 carbon dioxide sensor and the SPS30 particle sensor on an 80 x 40 mm carrier) 120 mm above the tray. PETG, printed standing up, 40 % infill.

**How to make it.**

1. Print a 20 x 20 x 176 mm post with two 4.5 mm holes through it front to back, 56 and 69 mm up from the foot, a 4.5 mm hole 15 mm deep down its top end, and a 6 mm channel down one side for the leads.
2. Mount the four reference sensors on their carrier as their makers describe.

**How it fits the parts next to it.** The foot stands on the chamber floor with one face flat against the back of the tray rail, held by two M4 nylon screws into the rail. The carrier screws onto the top with one M4 nylon screw. The leads run down the channel to a cable gland.

**Check before moving on.** The mast stands upright; the references clear the mixing fan by 30 mm.

### 3.11 Dryer socket

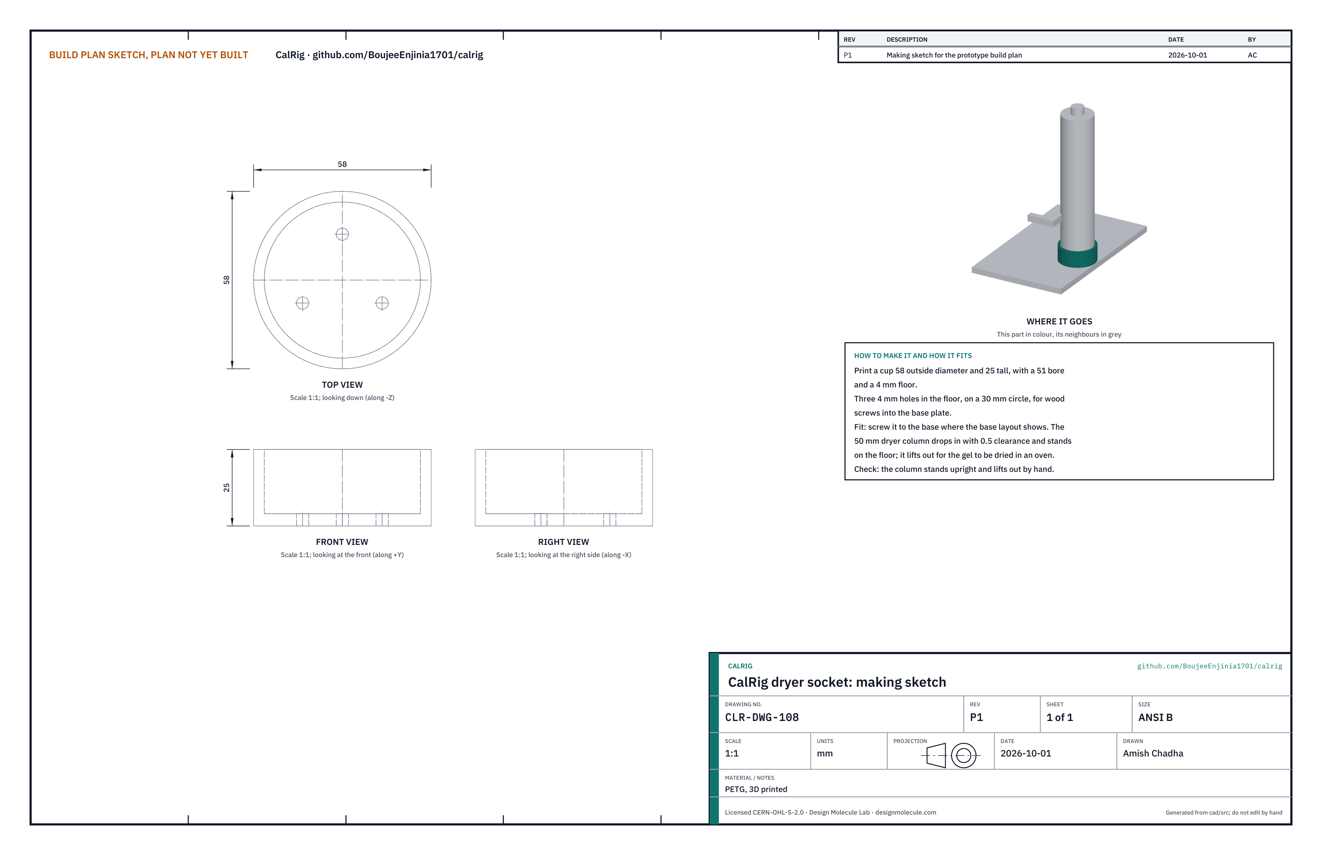
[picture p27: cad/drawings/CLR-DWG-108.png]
Figure 19. Making sketch of the dryer socket


*Figure 19. Dryer socket making sketch (CLR-DWG-108).*

**What it is and what it is made from.** A cup that holds the 50 mm dryer column upright on the base. PETG, printed.

**How to make it.** Print a cup 58 mm outside diameter and 25 mm tall with a 51 mm bore, a 4 mm floor and three 4 mm screw holes on a 30 mm circle.

**How it fits the parts next to it.** Screw it to the base where Figure 3 shows. The column drops in with 0.5 mm clearance and lifts out so the gel can be dried in an oven.

**Check before moving on.** The column stands upright and lifts out by hand.

### 3.12 Jar rack

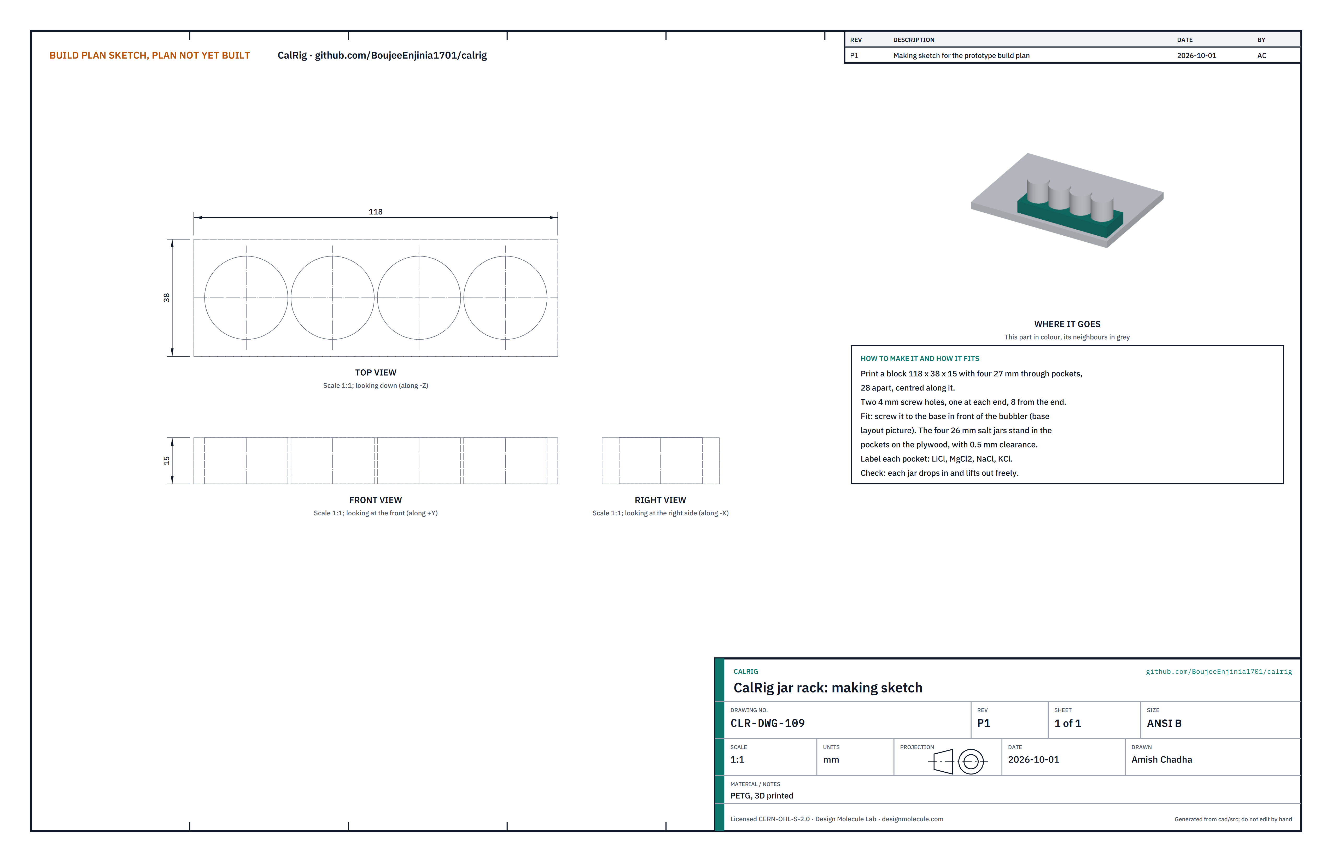
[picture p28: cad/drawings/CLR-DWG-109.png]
Figure 20. Making sketch of the jar rack


*Figure 20. Jar rack making sketch (CLR-DWG-109).*

**What it is and what it is made from.** A block that keeps the four salt jars upright and in order. PETG, printed.

**How to make it.** Print a block 118 x 38 x 15 mm with four 27 mm pockets 28 mm apart and a 4 mm screw hole 8 mm from each end. Label the pockets LiCl, MgCl2, NaCl and KCl.

**How it fits the parts next to it.** Screw it to the base in front of the bubbler (Figure 3). The 26 mm jars stand on the plywood in the pockets with 0.5 mm clearance.

**Check before moving on.** Each jar drops in and lifts out freely.

### 3.13 Door

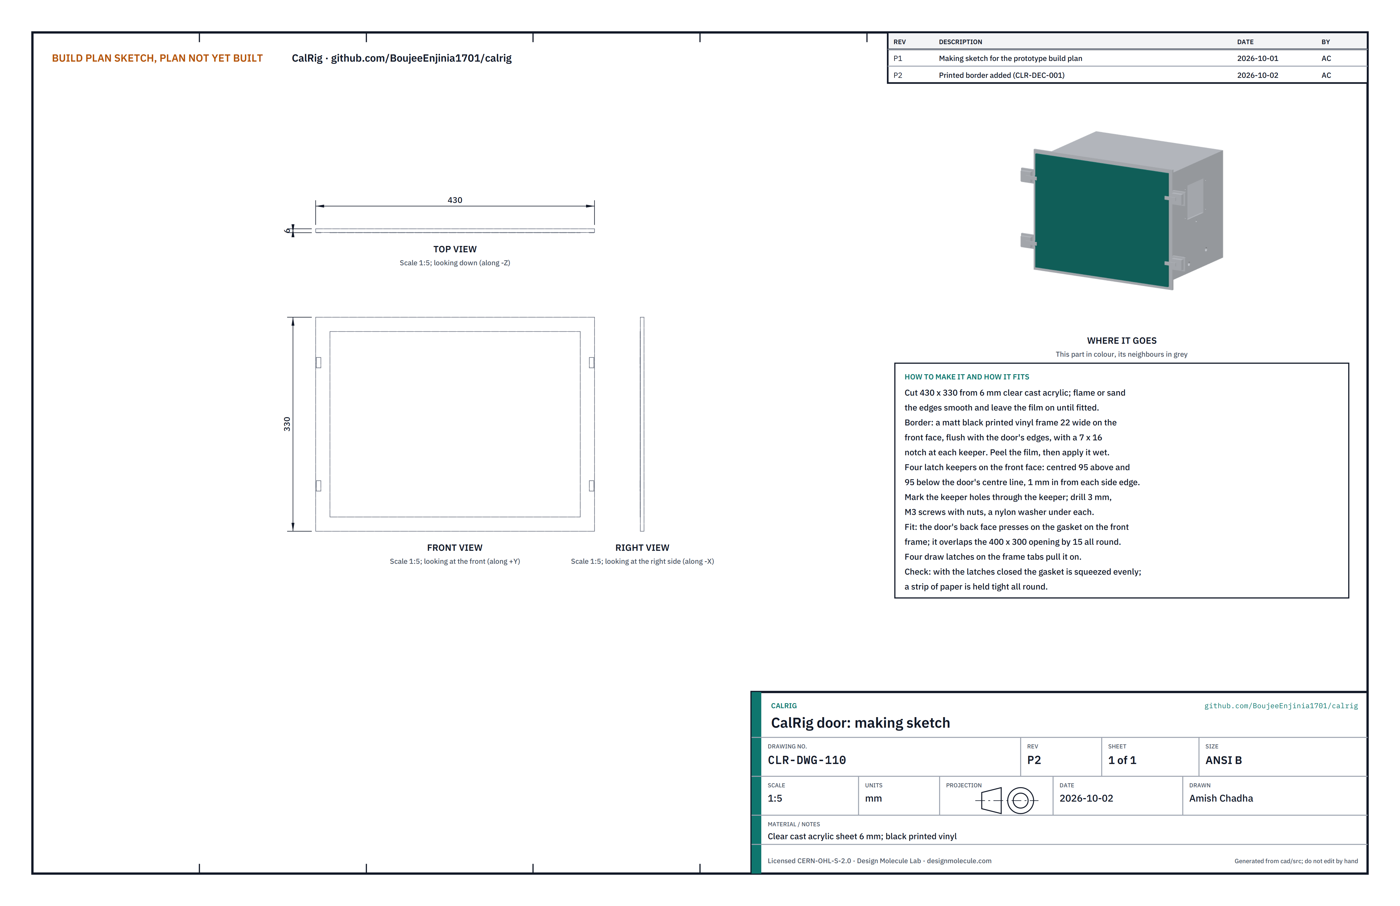
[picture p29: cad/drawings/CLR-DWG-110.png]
Figure 21. Making sketch of the door


*Figure 21. Door making sketch (CLR-DWG-110).*

**What it is and what it is made from.** The clear front of the chamber, held against the gasket by four draw latches, with a printed black border round its edge. Clear cast acrylic sheet 6 mm and printed vinyl.

**How to make it.**

1. Cut 430 x 330 mm. Sand or flame the edges smooth and leave the protective film on until it is fitted.
2. Peel the film from the front face and apply the border: a matt black printed vinyl frame 22 mm wide, flush with the door's edges, with a 7 x 16 mm notch at each keeper position. Apply it wet and squeeze out the bubbles.
3. Place a latch keeper on the front face at each latch: centred 95 mm above and 95 mm below the door's centre line, 1 mm in from each side edge. Mark the holes through the keeper, drill 3 mm, and fit M3 screws with nuts and a nylon washer under each.

**How it fits the parts next to it.** The back face presses on the gasket on the front frame and overlaps the 400 x 300 mm opening by 15 mm all round. The latches on the frame tabs hook the keepers (Figure 27).

**Check before moving on.** The border lies flat with no bubbles at the edges. With the latches closed, a strip of paper trapped between door and gasket is held tight all round.

### 3.14 Door panel

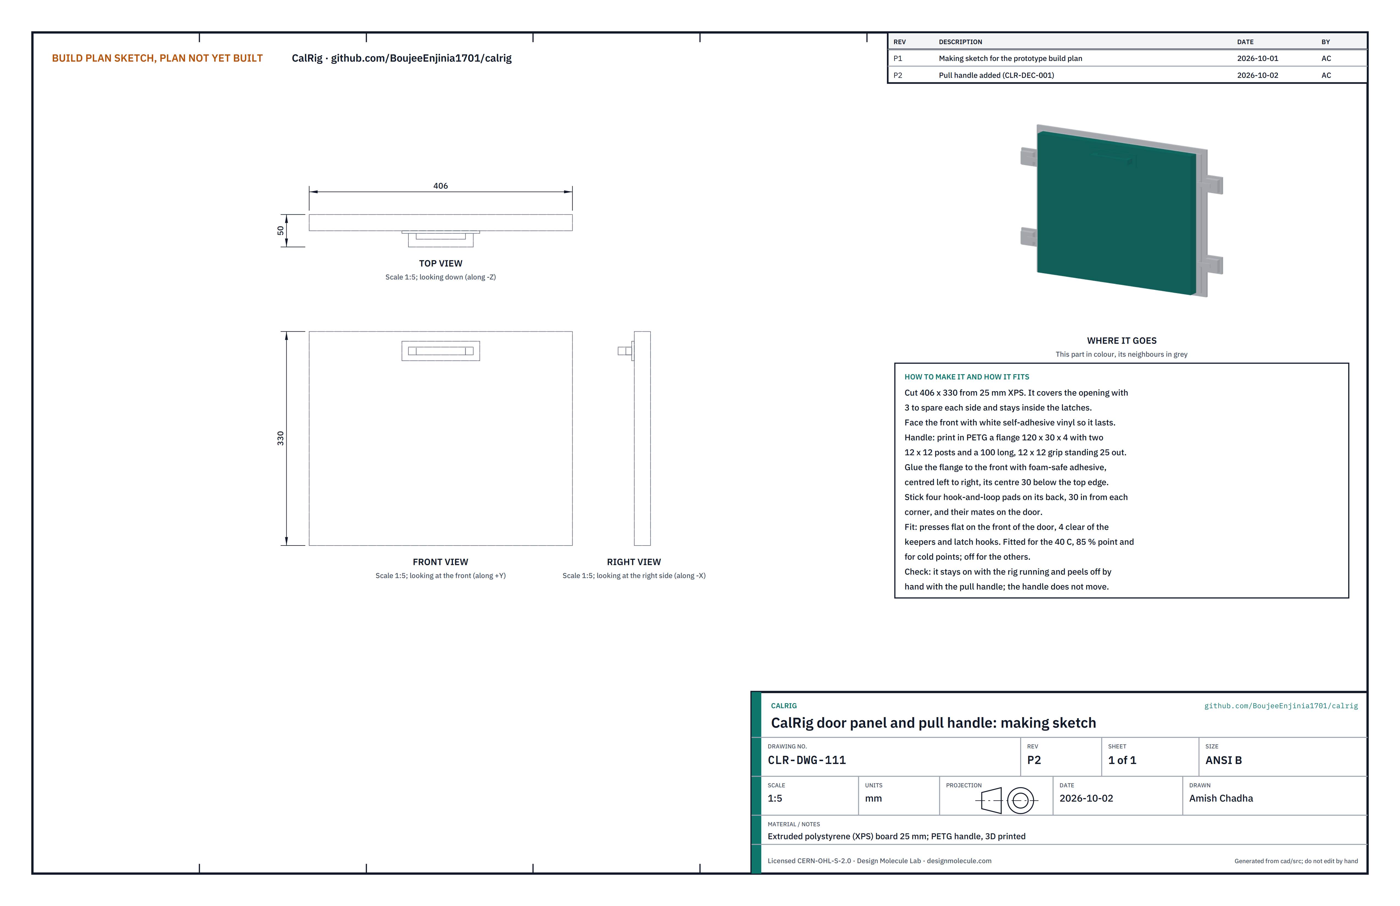
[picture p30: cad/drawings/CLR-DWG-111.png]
Figure 22. Making sketch of the door panel


*Figure 22. Door panel and pull handle making sketch (CLR-DWG-111).*

**What it is and what it is made from.** A removable foam panel that insulates the door for the hot, humid set point and for cold points, with a pull handle on its front. Extruded polystyrene board 25 mm; the handle is PETG, printed.

**How to make it.**

1. Cut 406 x 330 mm, face the front with white self-adhesive vinyl, and stick four hook-and-loop pads on its back, 30 mm in from each corner, with their mates on the door.
2. Print the pull handle: a flange 120 x 30 x 4 mm, two 12 x 12 mm posts and a grip 100 mm long and 12 x 12 mm in section, standing 25 mm out from the flange.
3. Glue the flange to the front with foam-safe adhesive, centred left to right, its centre 30 mm below the top edge. Leave it a day before pulling on it.

**How it fits the parts next to it.** It presses flat on the front of the door between the latches, 4 mm clear of the keepers and latch hooks, and covers the opening with 3 mm to spare each side.

**Check before moving on.** It stays on with the fans running and peels off by the handle without the handle moving.

### 3.15 Front badge and status light

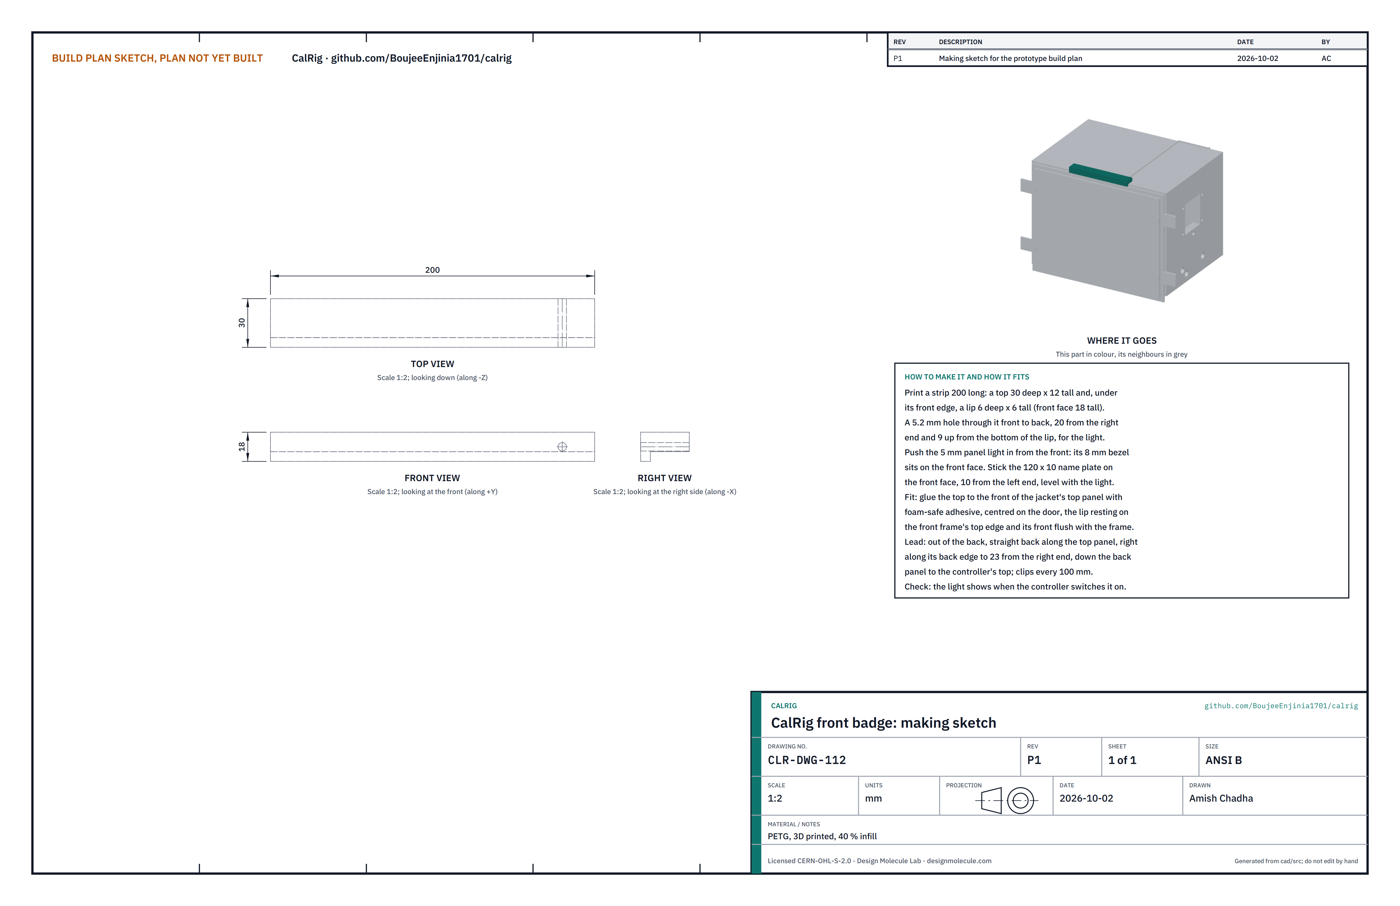
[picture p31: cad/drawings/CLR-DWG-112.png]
Figure 23. Making sketch of the front badge


*Figure 23. Front badge making sketch (CLR-DWG-112).*

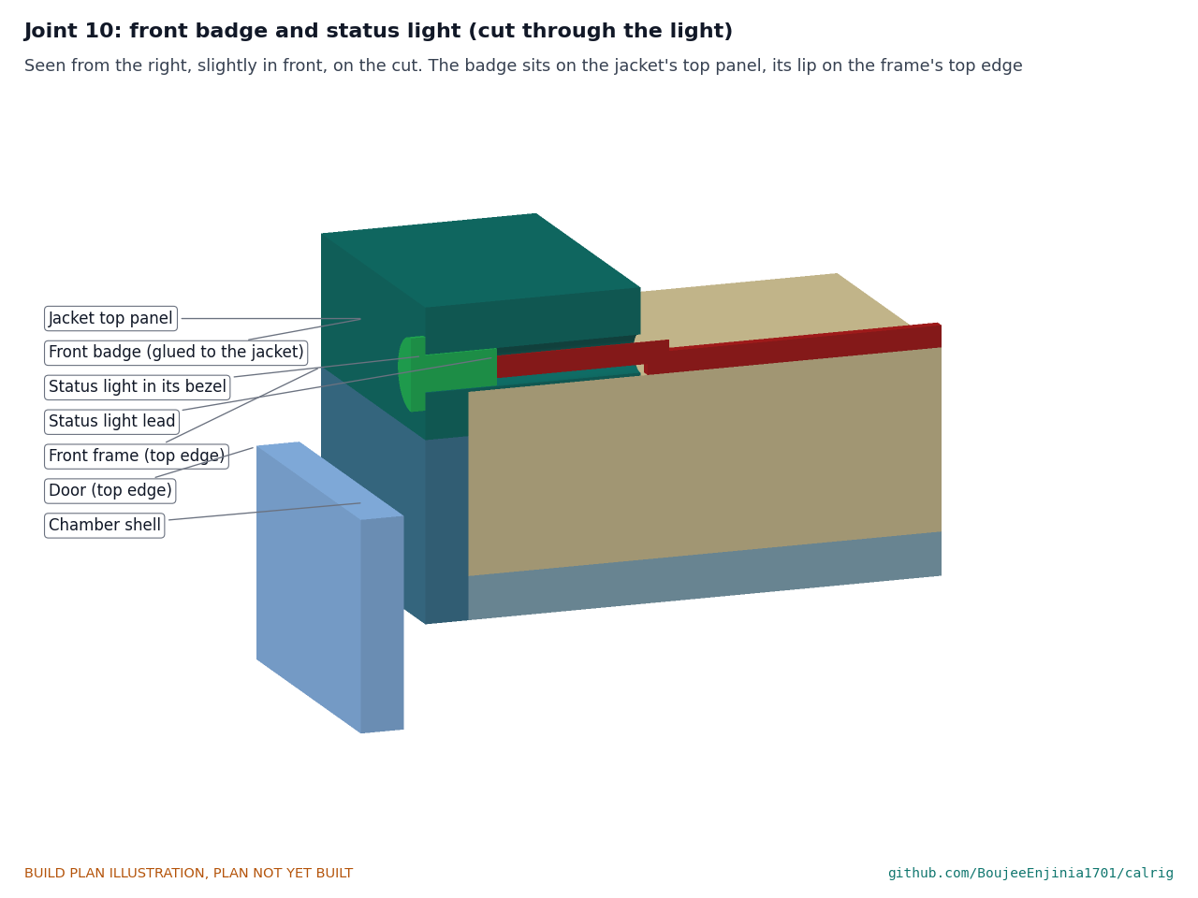
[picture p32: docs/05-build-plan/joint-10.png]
Figure 24. Joint 10: front badge and status light


*Figure 24. Cut through the light: the badge sits on the jacket's top panel with its lip on the front frame's top edge; the light's lead leaves through the back of the badge.*

**What it is and what it is made from.** A strip on the front of the rig that carries the name plate and a status light, so a run can be seen from across the room. PETG, printed, 40 % infill; a bought 12 V panel light (5 mm, in an 8 mm bezel with its resistor built in); a 120 x 10 mm name plate label; a two-core 0.25 mm² lead about 0.9 m long with a plug for the controller.

**How to make it.**

1. Print a strip 200 mm long: a top 30 mm deep and 12 mm tall and, under its front edge, a lip 6 mm deep and 6 mm tall, so the front face is 18 mm tall.
2. Include a 5.2 mm hole through it from front to back, 20 mm from the right-hand end and 9 mm up from the bottom of the lip.
3. Push the panel light in from the front so its bezel sits on the front face, and feed its lead out of the back.
4. Stick the name plate on the front face, 10 mm from the left-hand end, level with the light.

**How it fits the parts next to it.** Glue the top to the front of the jacket's top panel with foam-safe adhesive, centred on the door, with the lip resting on the front frame's top edge and its front flush with the frame (Figure 24). Run the lead straight back along the top panel, then right along the panel's back edge to 23 mm from its right-hand end, then down the back panel to the top of the controller, with a stick-on clip every 100 mm. Plug it into the controller's status light output.

**Check before moving on.** The badge does not touch the door or the door panel; the light comes on when the controller switches it.

### 3.16 Air loops and wiring

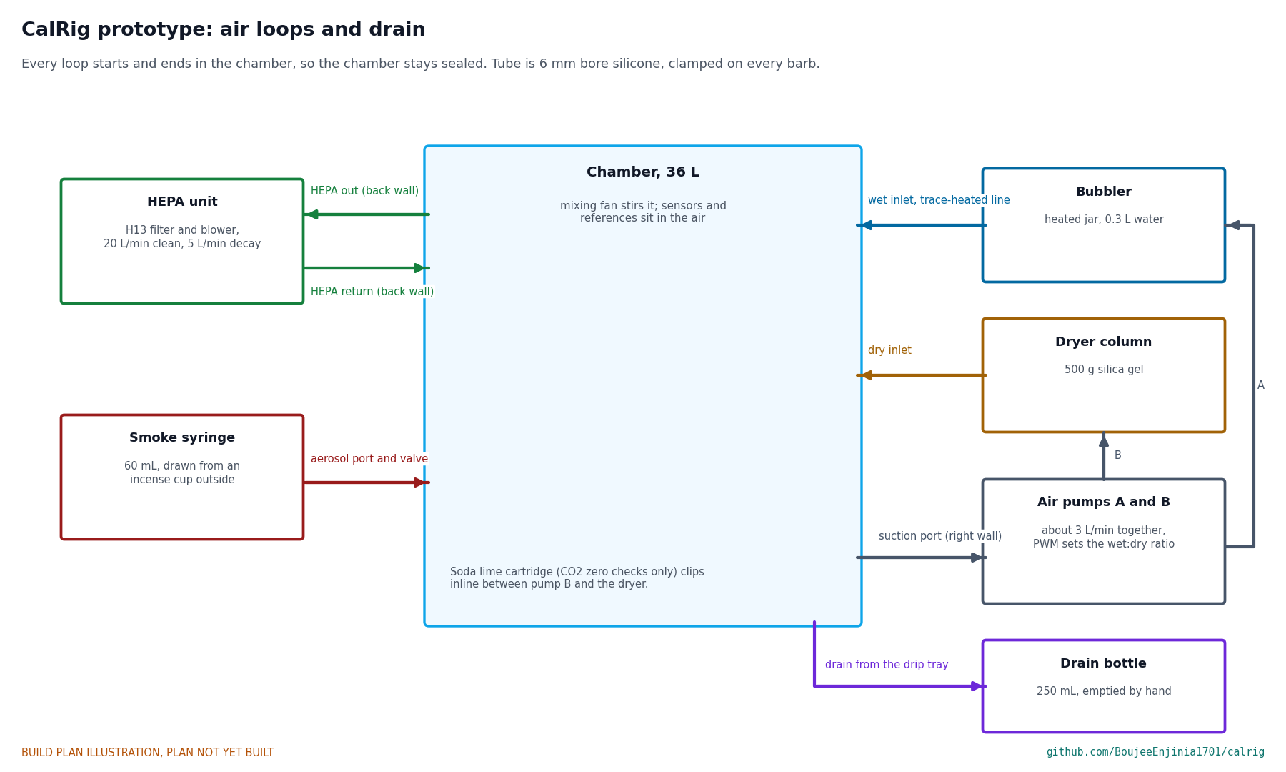
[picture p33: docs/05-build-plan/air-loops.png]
Figure 25. Air loops and drain


*Figure 25. Every air loop starts and ends in the chamber, so the chamber stays sealed.*

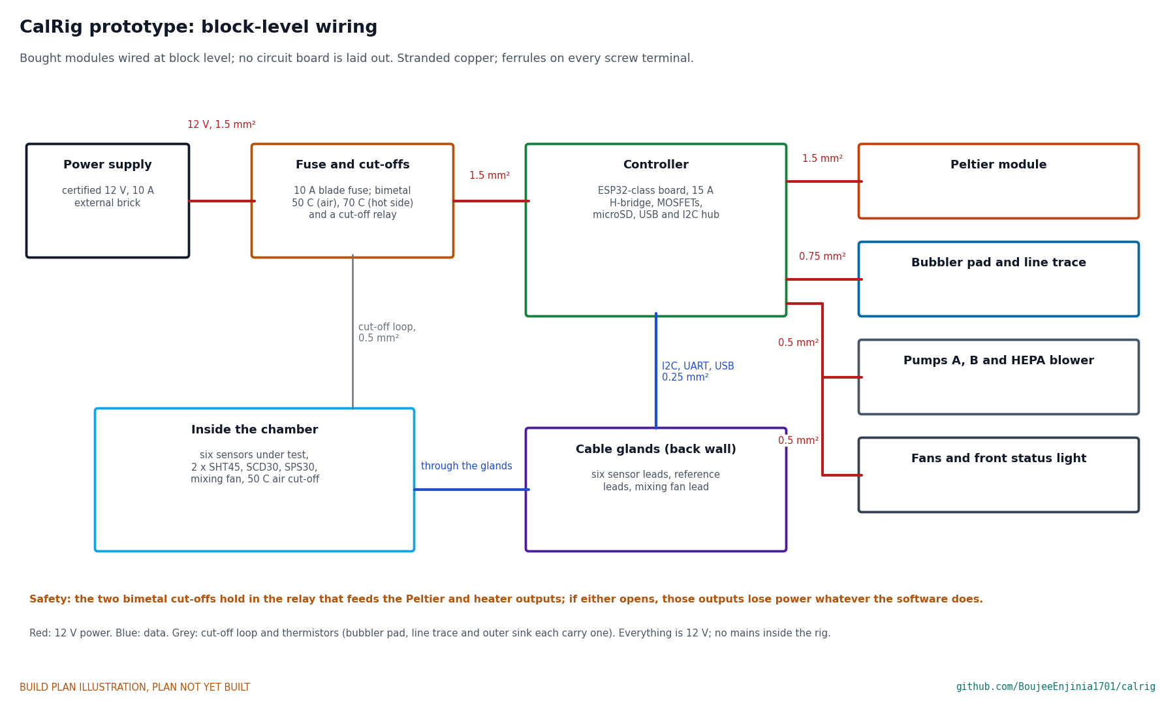
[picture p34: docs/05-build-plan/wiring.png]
Figure 26. Block-level wiring


*Figure 26. Block-level wiring with wire sizes. No circuit board is laid out at this stage; bought modules stand in for the power board.*

The power board in the bill of materials is a set of bought modules for this prototype:

*Table 2. Modules that make up the controller and power board.*

| Module | What to buy |
| --- | --- |
| Controller | ESP32-class development board with a microSD socket and a USB and I2C hub for the six sensors and the references |
| Heat pump driver | 12 V H-bridge rated 15 A or more, so the controller can heat or cool |
| Fan, pump and heater switches | Logic-level MOSFET modules, one per load, with flyback diodes on the fans and pumps; one more output for the front status light |
| Cut-offs | Two normally closed bimetal switches, 50 °C (stuck to the inside of the top, near the fan) and 70 °C (screwed to the outer sink's base), in series with the coil of a 12 V relay rated 10 A that feeds the heat pump and heater outputs |
| Fuse | 10 A blade fuse in an inline holder at the supply input |

Wire it like this, with stranded copper and a ferrule on every screw terminal:

1. Supply to the fuse, and the fuse to the controller's power input: 1.5 mm² (16 AWG).
2. Heat pump driver to the module: 1.5 mm².
3. Heater switch to the bubbler pad and line trace: 0.75 mm² (18 AWG).
4. Switches to the pumps, HEPA blower and fans: 0.5 mm² (20 AWG).
5. The two cut-offs in series with the relay coil: 0.5 mm², twisted.
6. Sensors and references through the cable glands to the hub: 0.25 mm² (24 AWG) or their own leads.
7. Thermistors on the bubbler pad, the line trace and the outer sink to the controller: 0.25 mm², twisted.
8. The front status light's lead to the controller's status light output: 0.25 mm², two cores, plugged in.

Run the tubes as Figure 25 shows, with 6 mm bore silicone tube and a clamp on every barb. The soda lime cartridge clips in between pump B and the dryer only for carbon dioxide zero checks.

**Check before moving on.** Every wire continues end to end; with the supply off, the 12 V bus reads open to ground; every wire and tube is labelled.

### 3.17 Bought components

Buy to specification, not brand. Line numbers are those of the bill of materials.

- **Peltier heat pump (line 5).** As section 3.7; sink bases at least 120 x 110 mm.
- **Mixing fan (line 6).** 120 mm, 12 V, about 85 m³/h free air, speed control, guard.
- **Reference cluster (line 8).** Two SHT45 breakouts, an SCD30 and an SPS30 that has been collocated at a monitoring station before use.
- **Bubbler (line 9).** 500 mL glass jar filled to 300 mL, air stone, 10 W 12 V heater pad with thermistor, 10 mm foam sleeve, 12 V diaphragm pump of about 1.5 L/min, outlet line with a 3 W trace heater under foam.
- **Dryer column (line 10).** 50 mm acrylic tube about 230 mm long with 500 g of indicating silica gel, and the second pump.
- **HEPA unit (line 11).** H13 filter cartridge and a 60 mm variable-speed blower in a housing with two 12 mm ports 80 mm apart, or one you can drill to match.
- **Aerosol port (line 12).** 16 mm bulkhead with a female Luer fitting, small ball valve, 60 mL syringe, metal incense cup.
- **Controller and power board (line 13).** As Table 2.
- **Power supply (line 14).** Certified external 12 V, 10 A supply with a regional mains lead.
- **Salt jars (line 15).** Four sealed jars of saturated LiCl, MgCl2, NaCl and KCl slurry with sensor lid adapters.
- **Door hardware (line 2).** Silicone D-section gasket about 10 mm wide; four small draw latches with keepers that fit a 41 x 40 mm tab; a matt black vinyl border 430 x 330 mm outside and 22 mm wide, cut by a sign or print shop.
- **Front badge parts (line 20).** A 12 V panel indicator light, 5 mm, in an 8 mm bezel with a built-in resistor; a name plate label 120 x 10 mm; two-core 0.25 mm² lead with a plug; stick-on cable clips.
- **Fittings (line 19).** As section 3.6, plus a 250 mL bottle with a lid and 6 mm drain tube.
- **Wiring and consumables (line 17).** Wire, ferrules, silicone tube and clamps, foam-safe adhesive, foil tape, acrylic solvent cement, M3 and M4 nylon and stainless screws, wood screws, hook-and-loop pads, labels.

## 4. Putting it together

In each picture the parts already fitted are grey and the parts being fitted are in colour, with an arrow showing the way they go in.

### Step 1: jacket bottom panel onto the base plate

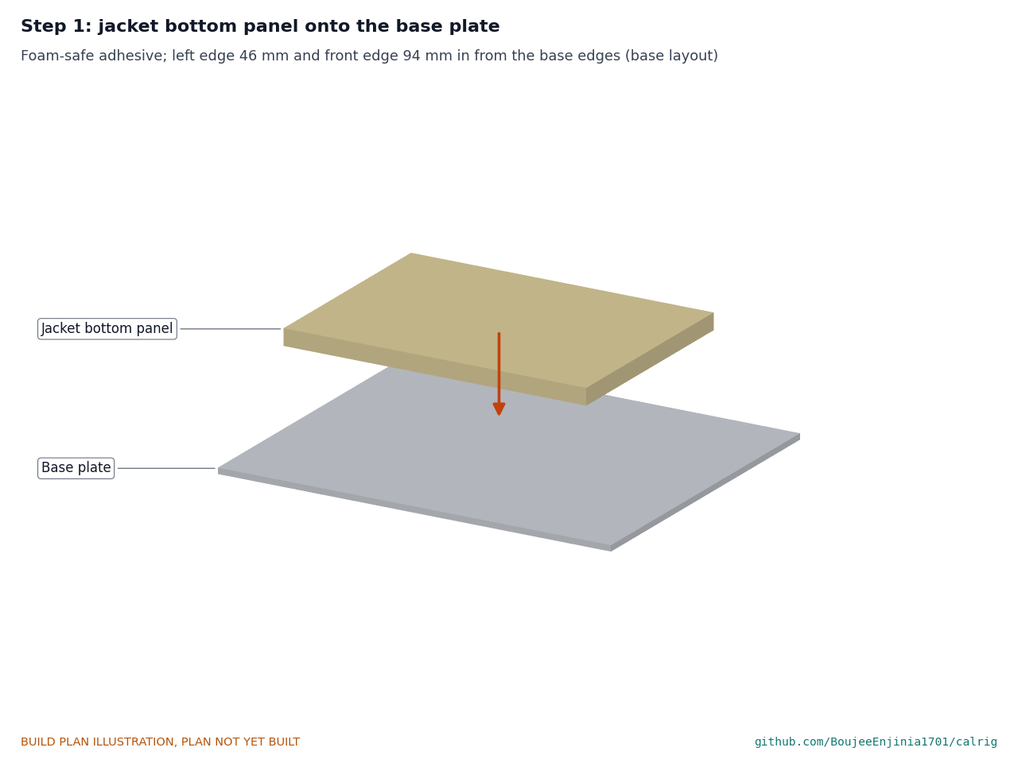
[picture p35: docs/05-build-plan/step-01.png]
Step 1


Foam-safe adhesive on the base; the panel 46 mm from the left edge and 94 mm from the front edge. Weigh it down until the adhesive sets.

### Step 2: chamber shell onto the jacket

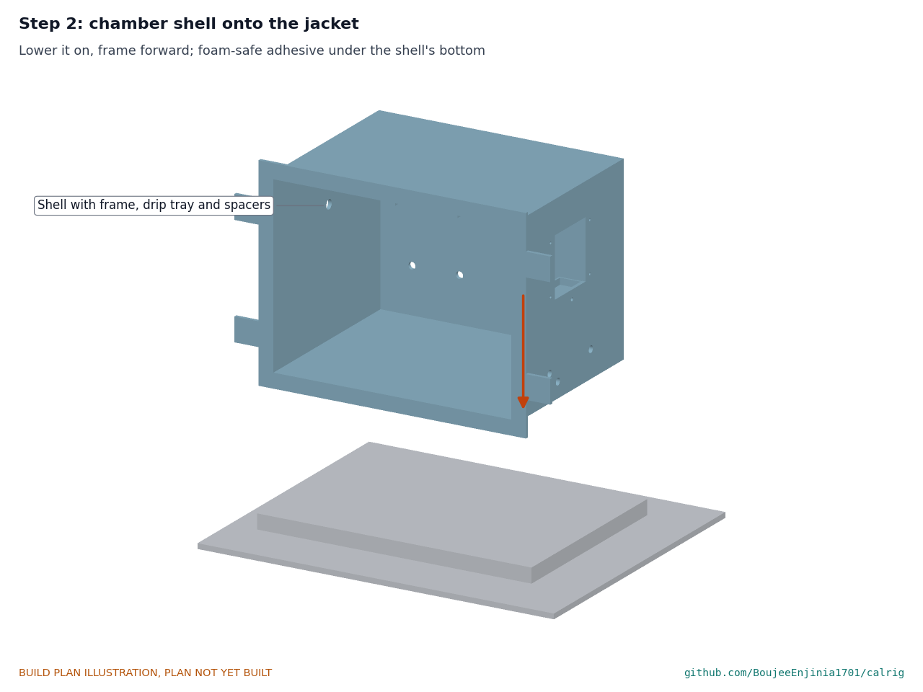
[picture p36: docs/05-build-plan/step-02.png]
Step 2


The shell, with its frame, drip tray and spacers already welded, goes down onto the bottom panel, frame forward, on a bead of foam-safe adhesive. Its sides line up with the panel's sides.

### Step 3: bulkheads, glands and aerosol port into the walls

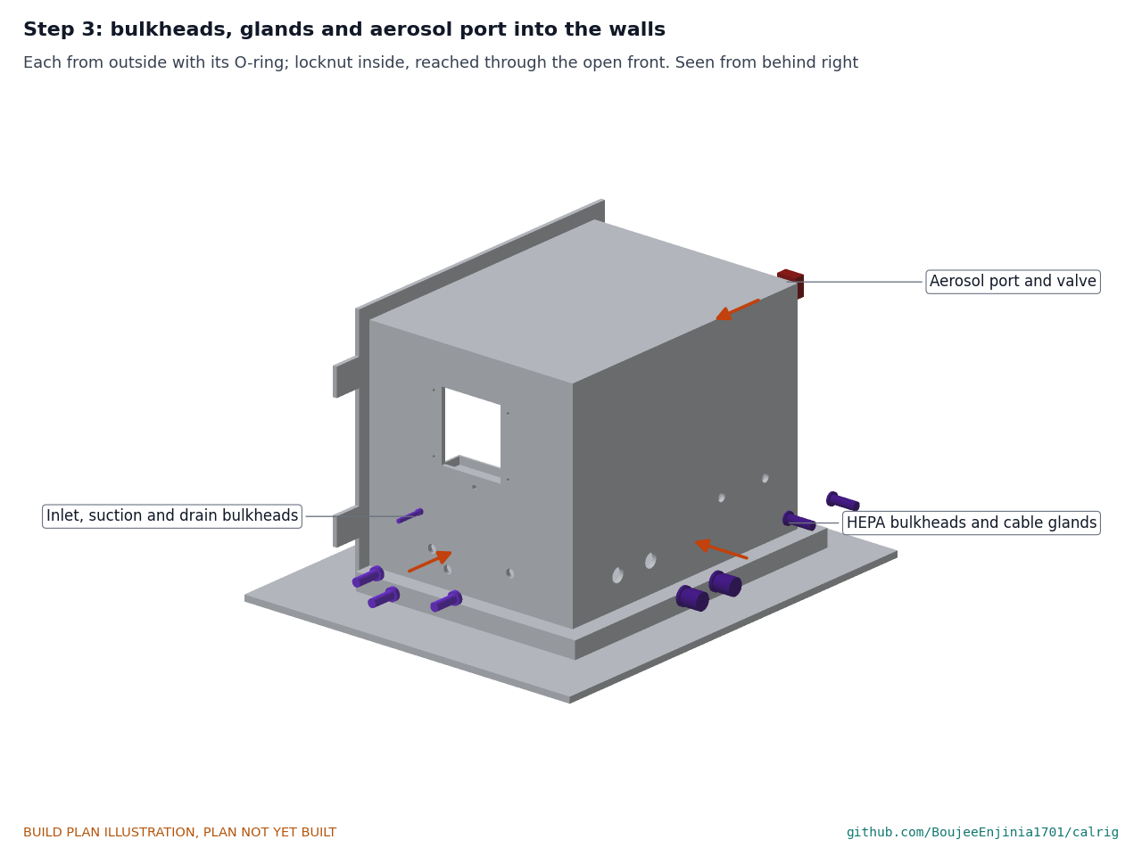
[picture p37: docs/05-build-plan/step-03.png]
Step 3


Each from outside with its O-ring on the outside face; nut or locknut tightened from inside through the open front. Seen from behind and to the right.

### Step 4: jacket back, side and top panels

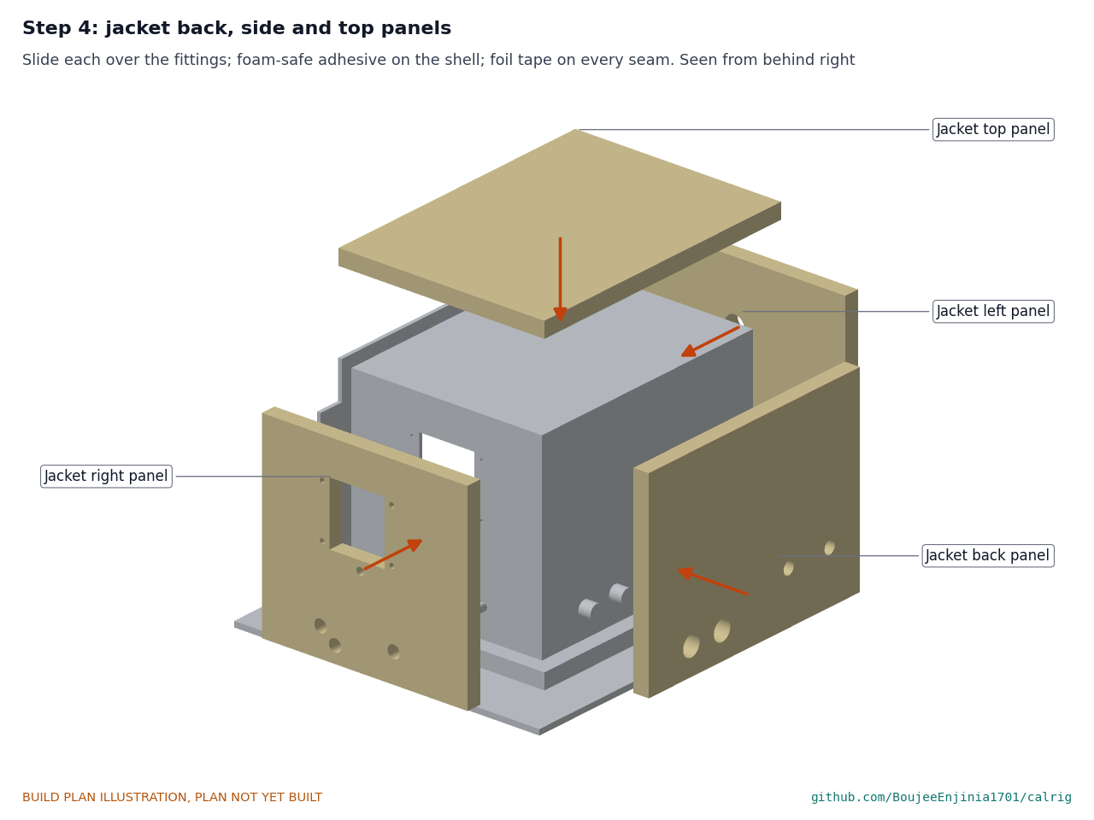
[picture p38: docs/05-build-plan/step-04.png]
Step 4


Slide each panel over the fittings, glue it to the shell with foam-safe adhesive and tape every seam with foil tape. Push the clamp sleeves into the right panel's four small holes. Fill round each fitting with foam offcut.

### Step 5: heat pump through the right wall

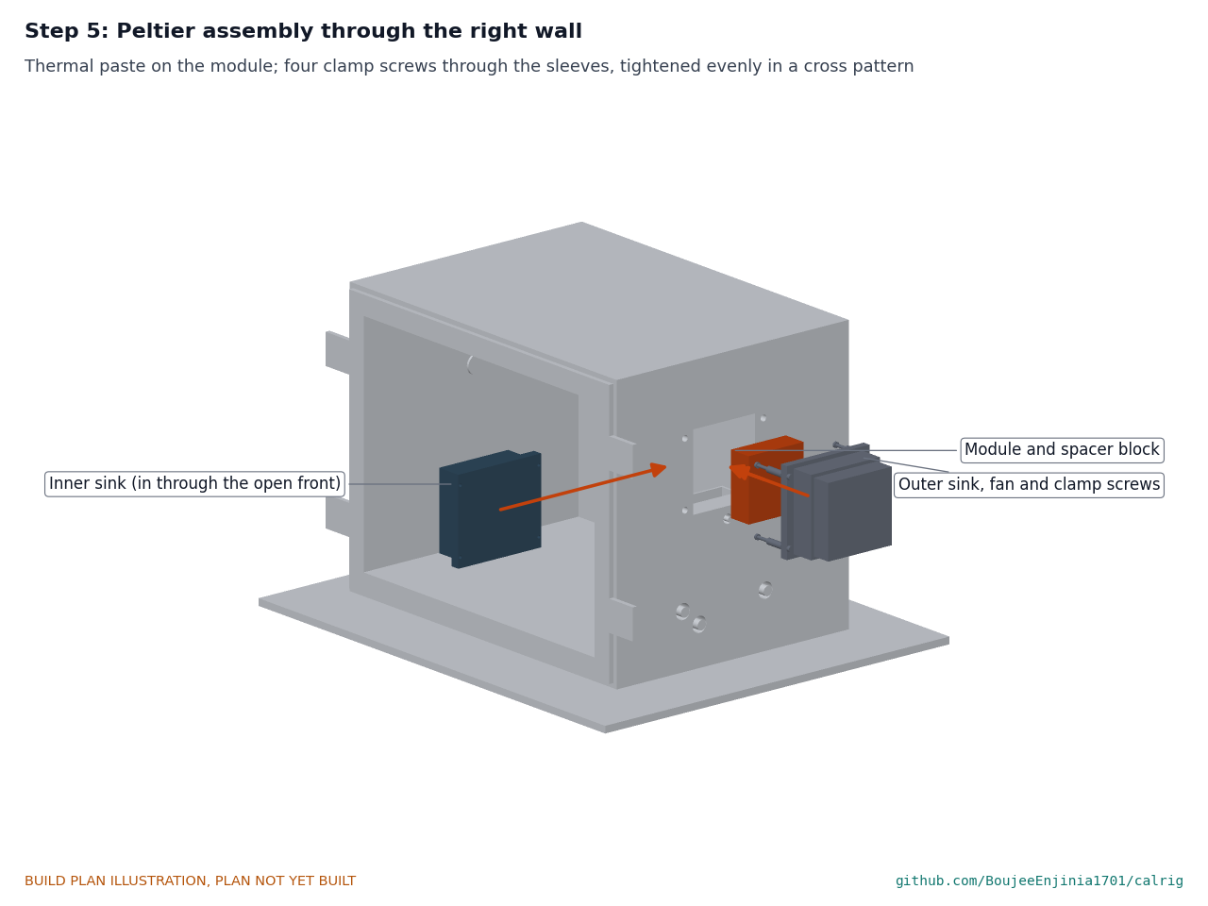
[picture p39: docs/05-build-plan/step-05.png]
Step 5


Inner sink in through the open front onto its gasket; module and spacer block into the opening with thermal paste; outer sink and fan on the outside; four clamp screws through both bases, the wall and the sleeves, tightened evenly in a cross pattern. Seal the gap round the block. **Hold point:** safety stop S2 before the heat pump is ever powered.

### Step 6: mixing fan onto its spacers

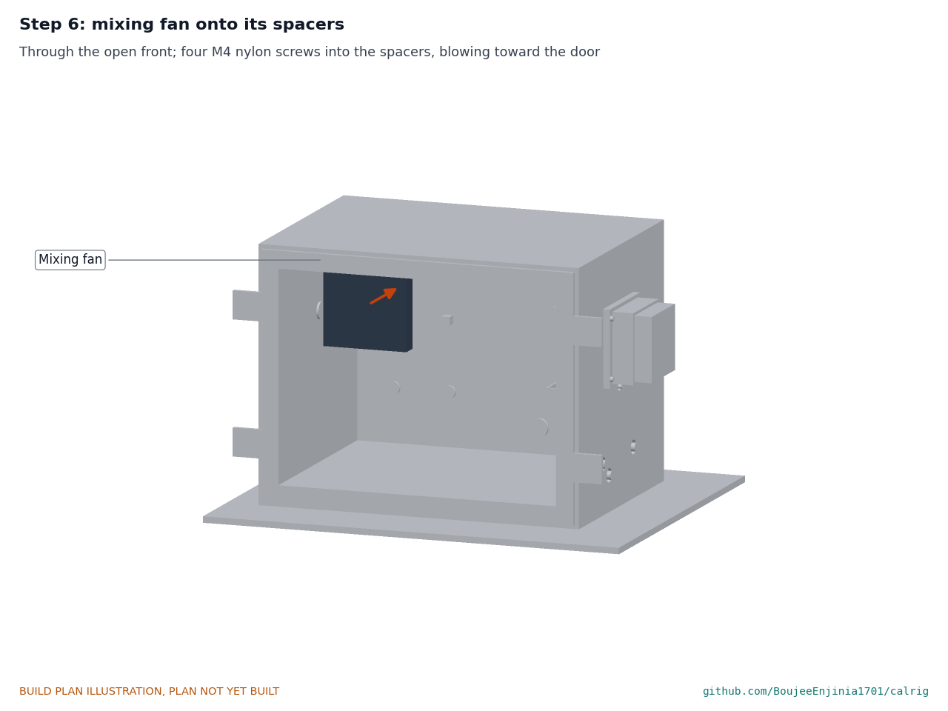
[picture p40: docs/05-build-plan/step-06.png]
Step 6


Through the open front; four M4 nylon screws into the spacers, the fan blowing toward the door. Run its lead down the back wall to a gland.

### Step 7: sensor tray in

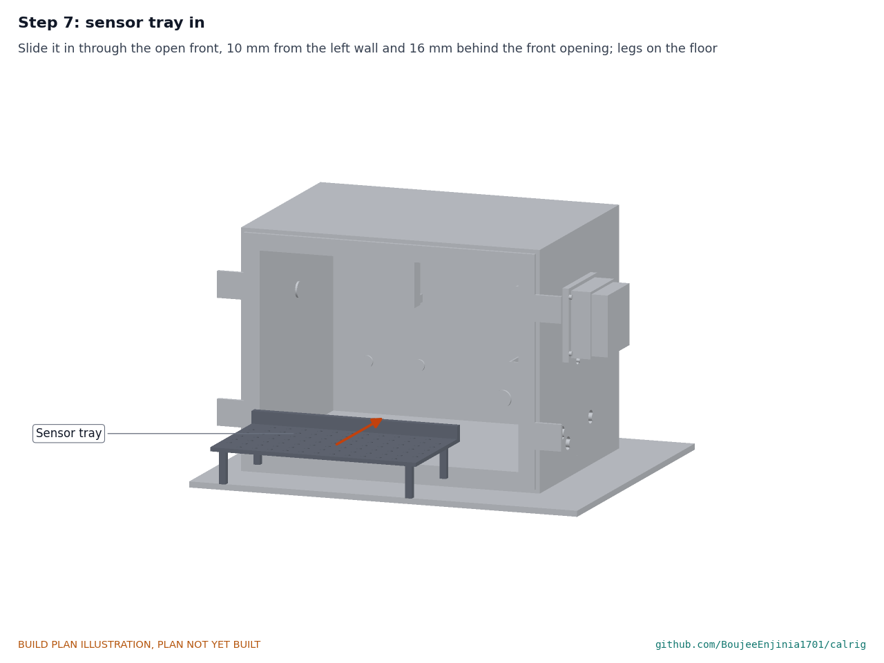
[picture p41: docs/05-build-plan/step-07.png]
Step 7


Slide it in through the open front, 10 mm from the left wall and 16 mm behind the front opening, legs on the floor.

### Step 8: reference mast and cluster

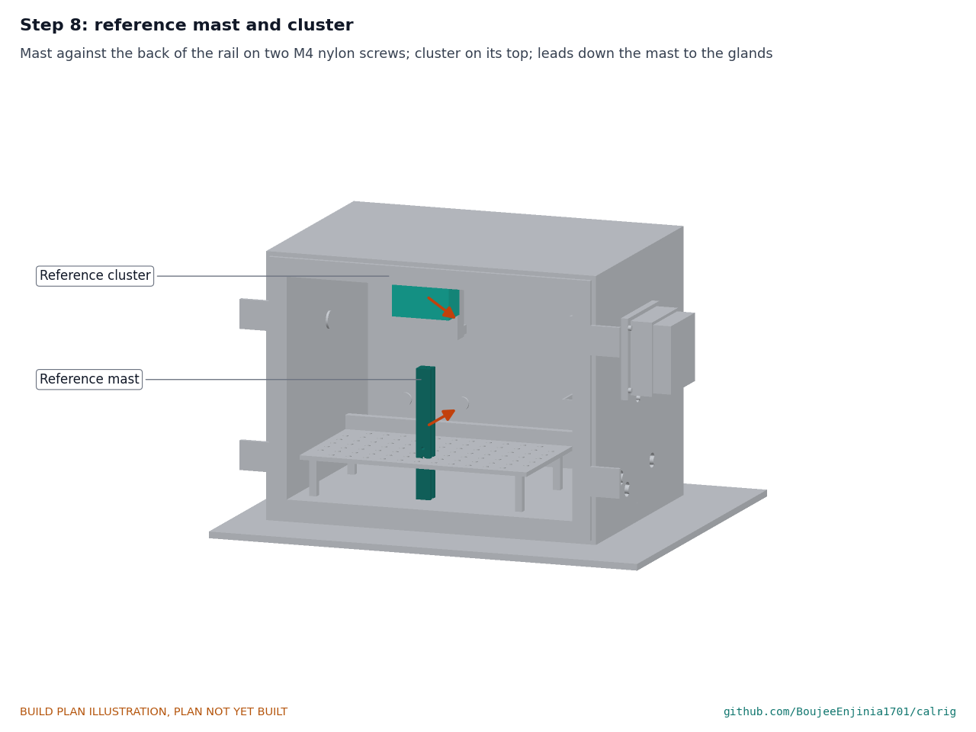
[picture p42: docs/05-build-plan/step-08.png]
Step 8


Mast against the back of the rail on two M4 nylon screws; carrier on its top. Run the reference and sensor leads through the multi-hole inserts of the glands and tighten the gland caps.

### Step 9: HEPA unit, controller and power supply onto the base

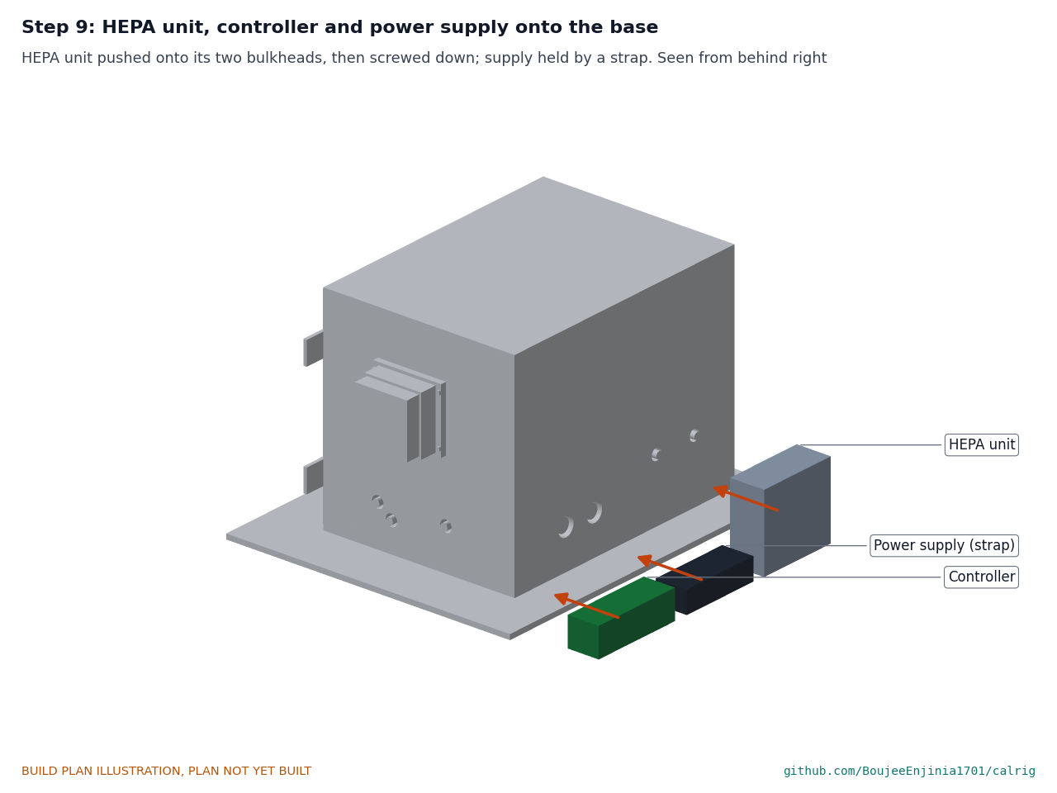
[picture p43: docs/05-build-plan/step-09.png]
Step 9


Push the HEPA unit onto its two fittings, clamp the joints and screw it down; screw the controller down; strap the supply down. Seen from behind and to the right. Wire as Figure 26, with the fuse out.

### Step 10: pumps, bubbler, dryer and drain bottle

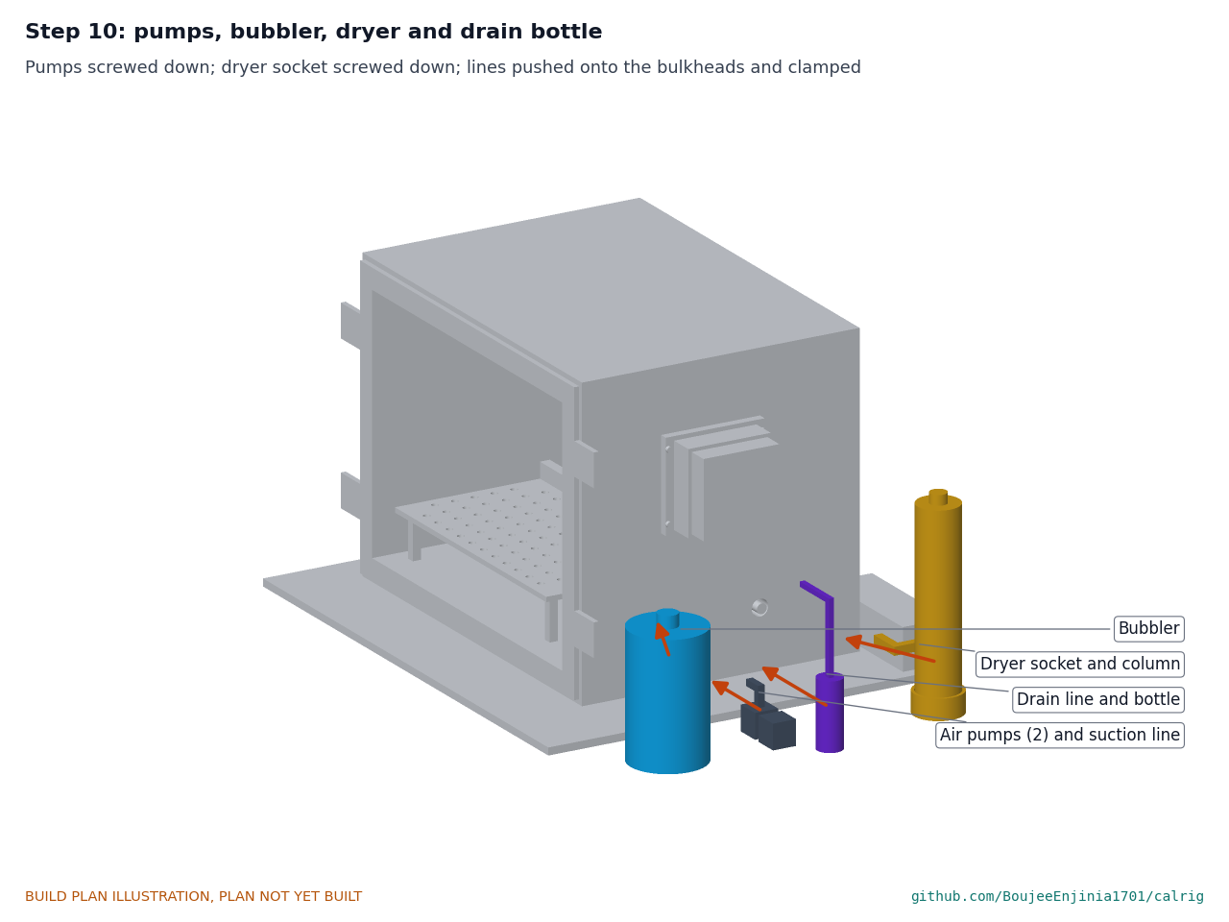
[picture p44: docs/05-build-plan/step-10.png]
Step 10


Screw the pumps and the dryer socket down; set the bubbler and the bottle on their pads; push each line onto its fitting and clamp it, as Figure 25. The bubbler stays empty until safety stop S3.

### Step 11: jar rack and salt jars

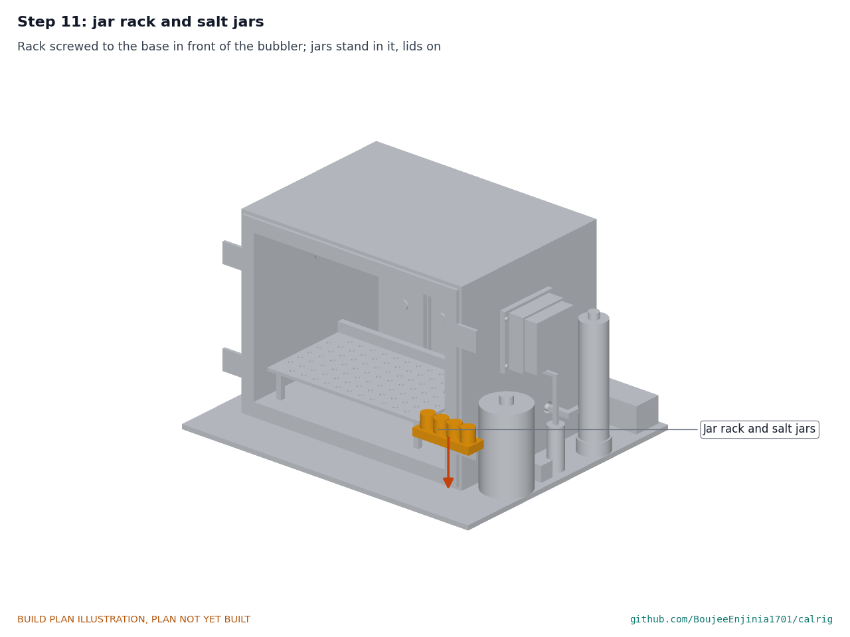
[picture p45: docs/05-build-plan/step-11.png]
Step 11


Screw the rack down in front of the bubbler; stand the four jars in it with their lids on.

### Step 12: front badge and status light lead

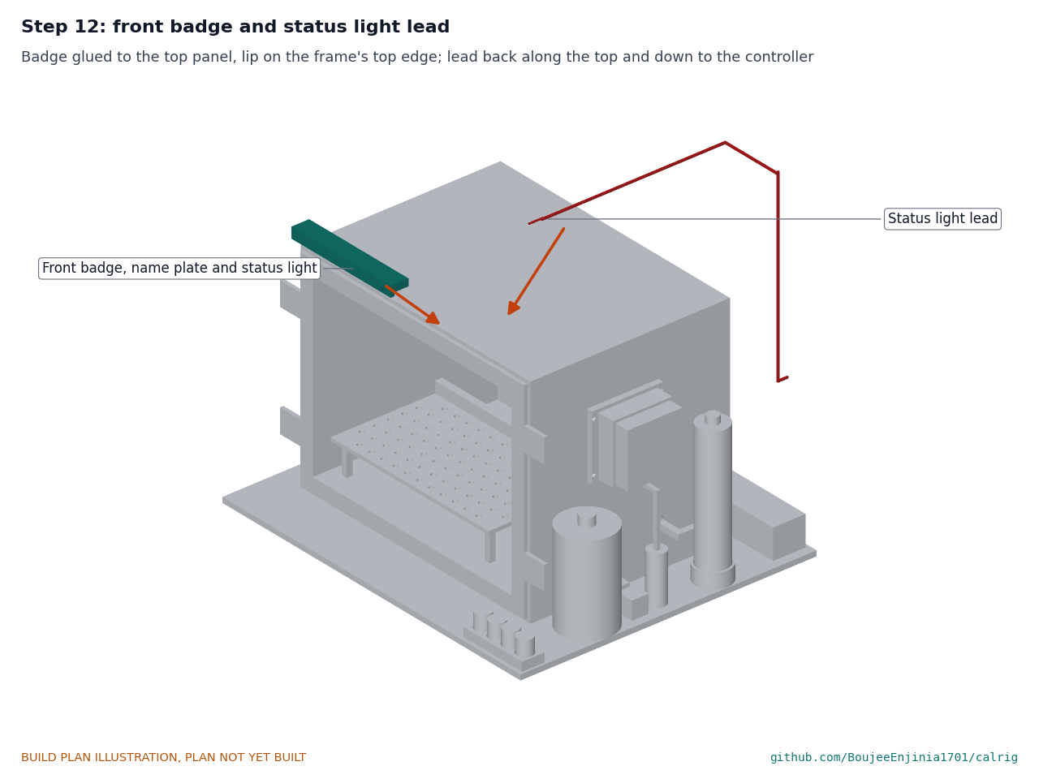
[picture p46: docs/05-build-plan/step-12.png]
Step 12


Glue the badge to the front of the top panel with its lip on the front frame's top edge (section 3.15). Run the lead back along the top, along the back edge and down the back panel, clipped every 100 mm, and plug it into the controller.

### Step 13: gasket, door and latches

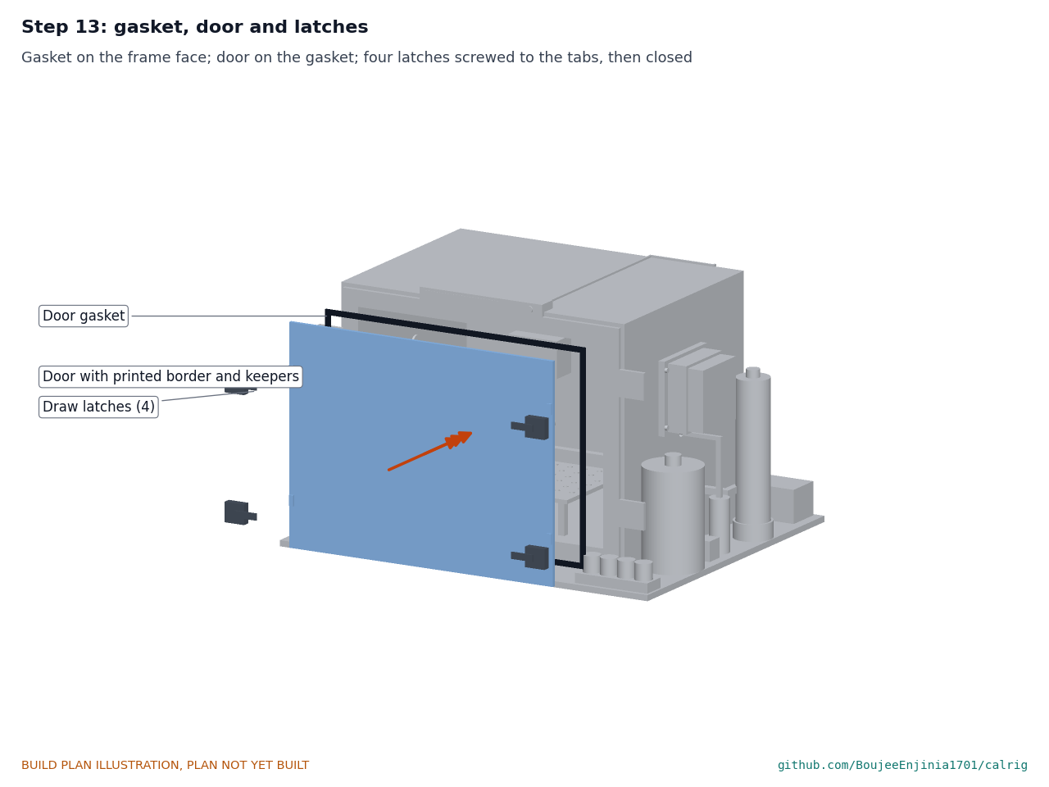
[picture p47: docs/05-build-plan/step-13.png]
Step 13


Stick the gasket on the frame's face, 4 to 12 mm outside the opening, with its joint at the bottom. Screw the four latches to the frame tabs, hold the door on the gasket and close the latches.

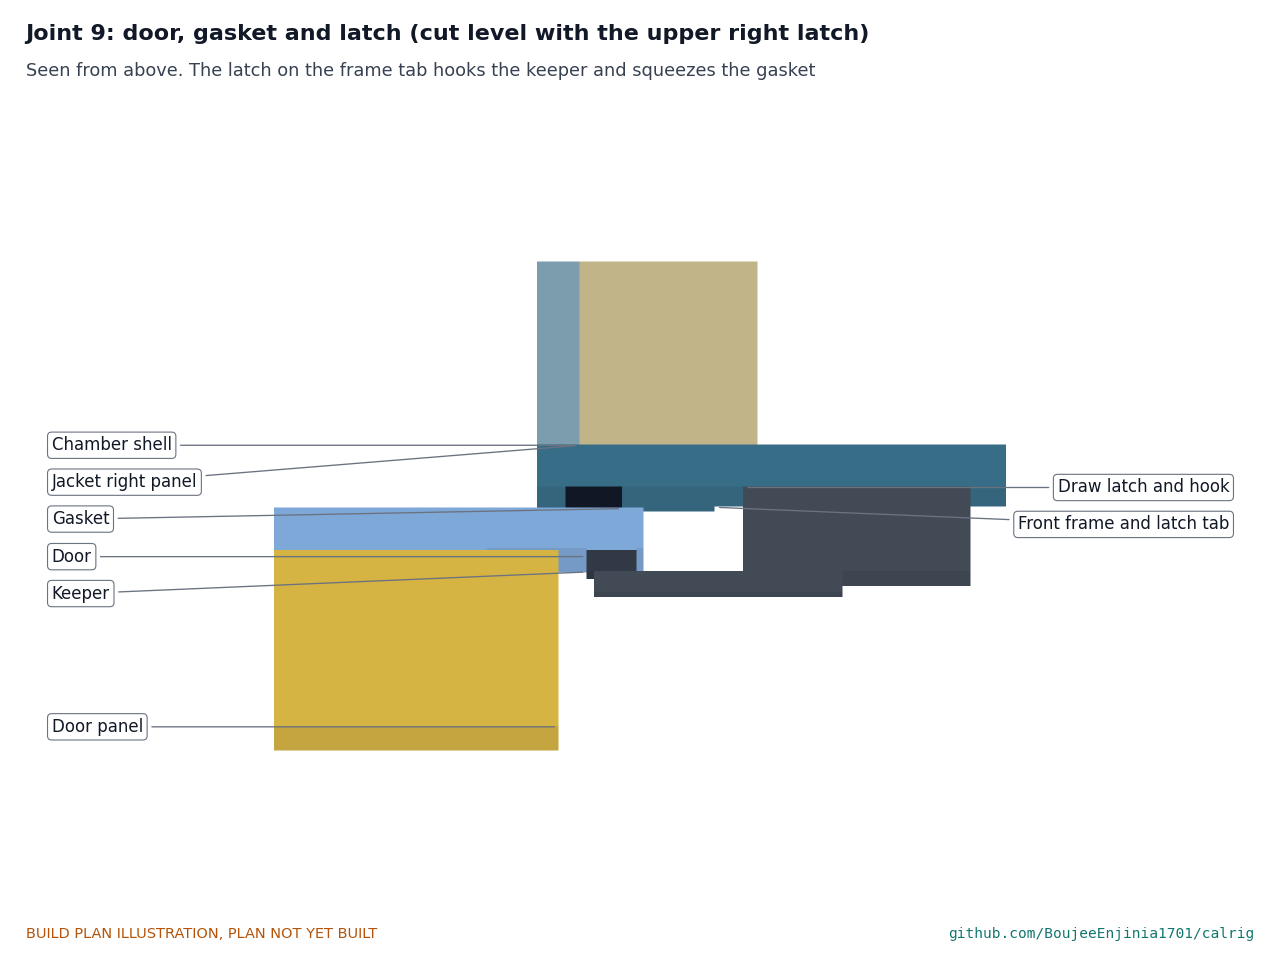
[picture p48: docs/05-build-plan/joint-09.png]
Figure 27. Joint 9: door, gasket and latch


*Figure 27. Cut level with the upper right latch: the latch on the frame tab hooks the keeper on the door and squeezes the gasket between door and frame.*

### Step 14: door panel

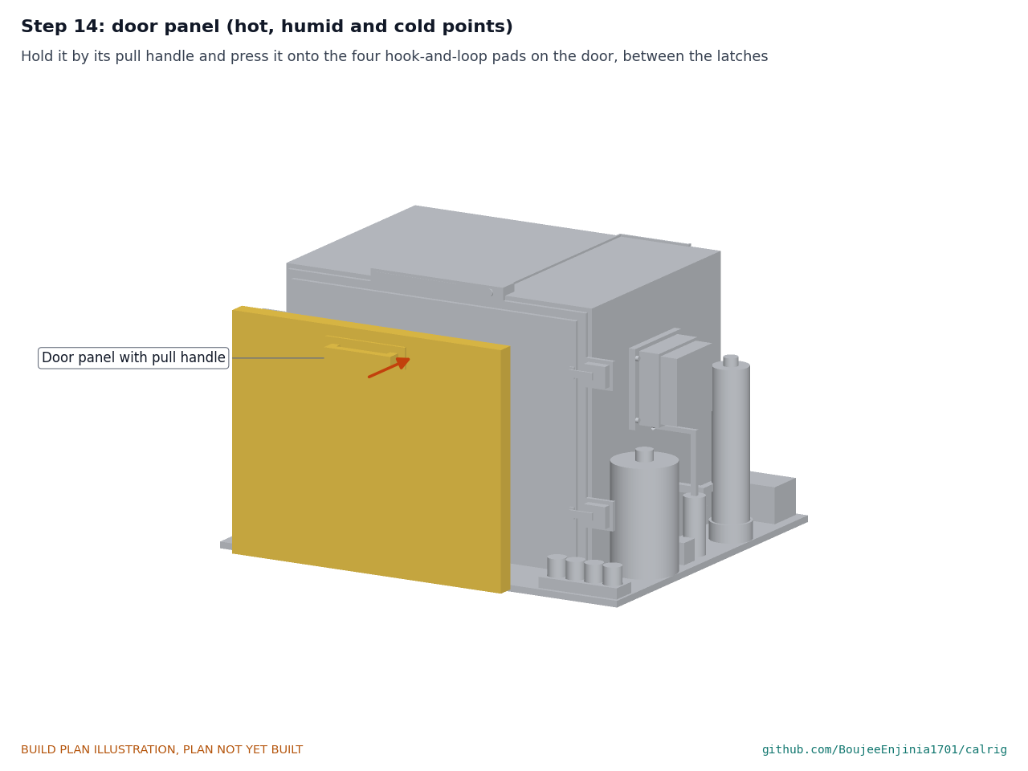
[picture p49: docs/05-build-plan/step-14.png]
Step 14


Hold the panel by its pull handle and press it onto the four hook-and-loop pads on the door, between the latches. It is fitted for the 40 °C, 85 % RH point and for cold points, and off for the others.

## 5. First checks

These are the checks a TRL 4 test report would record; this plan only lists them. Requirement numbers are those of CLR-REQ-001.

*Table 3. First checks.*

| Check | Requirement | How | Pass when |
| --- | --- | --- | --- |
| Shell leak | R2, R7 | 10 mm of water in the shell for an hour (section 3.3), before the jacket goes on | No water at any weld |
| Door seal | R2, R7 | Paper strip trapped at 20 points round the closed door | Held tight at every point |
| Fit of the heads | R10 | Six 90 x 70 x 50 mm blocks in the bays, door closed; leads through the glands | Everything fits; the gland caps seal round the leads |
| Fit of large heads | R10 | A 192 x 152 x 234 mm block on four bays and a 192 x 70 x 234 mm block on two bays, in each position, door closed | Each stands on the tray clear of the walls, fan, inner sink and references |
| Status light | R15 | Supply on, controller switching the light on and off | The light follows the controller; the lead stays clipped down |
| Fuse and supply | R15 | Supply on, fuse in, every load off, then the heat pump at full drive with all fans, pumps and heaters on | Bus current 7.5 A or less; no part warm but the loads |
| Cut-offs | R16 | Each bimetal switch warmed in a water bath with a thermometer | The relay drops out at 50 °C and at 70 °C (within the switch's tolerance) and the heat pump and heaters lose power |
| Heat pump direction | R1 | Short runs at low drive in each direction | The inner sink warms when heating and cools when cooling; the outer fan runs whenever the module is powered |
| Air loops | R2 | Each pump and the HEPA blower in turn, a soap film on each joint | Bubbles leave only where Figure 25 says air goes; no leak at any barb |
| Drain | R2 | 20 mL of water poured into the drip tray | All of it reaches the bottle |
| Clean-down | R7 | HEPA unit at full speed, references logging | Particle reading falls below 2 µg/m³ |
| Size and mass | R13 | Tape measure; bathroom scale with and without the rig held | Within 600 x 500 mm and 400 mm high (383 mm estimated); 14 kg or less (13.9 kg estimated) |

## 6. Safety stops

Stop at each point. Carry on only when everything listed is true.

- **S1. Before cutting and welding acrylic.** Laser cutting in a cutter with working extraction; solvent cement used in a ventilated space with gloves and eye protection; no flame near the cement.
- **S2. Before the heat pump is powered.** Both sinks clamped flat with paste on the module; the outer fan runs whenever the module is powered (wired so it cannot be switched off while the module is on); both cut-offs wired in series with the relay coil and checked as in section 5; the 10 A fuse in place; the supply is certified and undamaged.
- **S3. Before the bubbler is filled and its heater powered.** Thermistors fitted to the pad and the line trace; the cut-off relay feeds the heater; the jar stands in its foam sleeve on its pad; the electronics stand behind the chamber, higher than any spilled water can reach. Fill with distilled water only.
- **S4. Before the first smoke run.** The room is ventilated; the incense cup stands outside the chamber on a non-combustible surface; the door is closed and latched; the HEPA unit is running. The door opens only after the references read below 5 µg/m³.
- **S5. Before handling soda lime or the salt slurries.** Gloves and eye protection on; containers labelled; children kept away. Exhaled-air carbon dioxide checks use a single-user bag and filter.
- **S6. Before the first unattended run.** One full sweep has been watched from start to finish, with the outer sink staying below 60 °C and the chamber air below 45 °C; the rig stands on a non-combustible bench away from paper and curtains.

## 7. Tools, skills and workspace

**Tools.** Laser cutter able to cut 6 mm cast acrylic (a maker space or a cutting service) or a fine-toothed saw and a router; acrylic solvent cement with a needle applicator; corner clamps and square blocks; fine-toothed saw or hot-wire cutter for foam board; drill with 3, 4.2 and 4.5 mm bits and a step drill to 20 mm; M3 and M4 taps; 3D printer able to print PETG (bed at least 120 x 60 mm, height 180 mm); screwdrivers and nut drivers; side cutters, wire strippers and a ferrule crimper; soldering iron; multimeter; digital thermometer; tape measure, steel rule and square; bathroom scale.

**Skills.** No certified trade is needed. Marking out, laser cutting or sawing acrylic, solvent welding, cutting foam board, drilling and tapping, 3D printing, crimping and soldering, and safe use of a 12 V supply. Everything runs at 12 V from a certified external supply; no mains wiring is part of this build.

**Workspace.** A bench about 1.2 x 0.8 m in a ventilated room; a flat surface to weld the shell square; a separate corner for solvent work; a sink for the leak check.

**Personal protective equipment.** Safety glasses for cutting, drilling, welding and soldering; nitrile gloves for solvent cement, soda lime and salts; a dust mask when sanding acrylic.

## 8. Where the numbers come from

- Model and constructability checks: `cad/src/model.py` (`python cad/src/model.py --check`, 116 checks); STEP and STL exports in `cad/step/` and `cad/stl/`.
- Pictures: `cad/src/build_plan_media.py`, using `.kit/build_views.py`; written to `docs/05-build-plan/` and `cad/drawings/CLR-DWG-101` to `CLR-DWG-112`.
- General arrangement: `cad/drawings/CLR-DWG-001.pdf`, Rev P5.
- Calculations: `docs/04-calcs/01-sizing.md` (CLR-CAL-001 v0.7) and `docs/04-calcs/sizing.py`; mass [A3], large heads [A4], heat capacity and ramps [B7, B8], power [J1], cut-offs [J2], cost [K1].
- Bill of materials: `bom/bom.csv` and `bom/bom-notes.md`.
- Decisions: `docs/decisions/0003-design-for-construction.md` (CLR-DDR-003), with CLR-DDR-001 and CLR-DDR-002; decisions and items to confirm in `docs/06-design-decisions.md` (CLR-DEC-001).
- Requirements: `docs/03-requirements.md` (CLR-REQ-001 v0.9).

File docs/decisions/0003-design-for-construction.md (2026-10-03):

---
doc_id: CLR-DDR-003
title: CalRig design for construction
project: CalRig
doc_type: Design decision record
version: "0.4"
status: Draft
date: '2026-10-02'
author: Amish Chadha
license: CERN-OHL-S-2.0
revisions:
- version: "0.1"
  date: '2026-10-01'
  author: Amish Chadha
  change: Changes that make the concept physically buildable, with the reason for each; made under Amish's 2026-09-30 instruction to make the design physically buildable; open for his review
- version: "0.2"
  date: '2026-10-01'
  author: Amish Chadha
  change: Budget treated as a value-engineering target; cost wording only, no number changed
- version: "0.3"
  date: '2026-10-02'
  author: Amish Chadha
  change: 'Accepted by Amish on 2026-10-02, including the recommendations for A2 and A3; A1 stays proposed'
- version: "0.4"
  date: '2026-10-02'
  author: Amish Chadha
  change: 'Consequences updated after the approved follow-ups: appearance model brought in line with the constructable design and render scenes exported; A2 margin now 0.08 kg'
---

# 0003: Design for construction

- **Date:** 2026-10-01
- **Status:** accepted. Amish, 2026-10-02: "i approve your recommendations for all 555 open decisions." This covers every change in Tables 1 and 2 and the recommendations for A2 and A3 in Table 3, now decided as recommended and recorded in the design decisions register (CLR-DEC-001). A1 was not one of the open decisions in the register; it stays proposed, and its recommendation (keep the design and re-price at purchase) is carried in the register's value engineering section.

## Context

On 2026-09-30 Amish approved the build plan format and asked for it across all repos, writing: "If you are realising that the design cannot be built as per concept - fix the design assumptions to match and be physically feasible as you draw the illustrations." The concept model of CLR-DDR-002 showed what CalRig does, but checking it part by part with build123d found twelve places where it could not be built as drawn: parts with no fixing, parts floating in the air, air loops with no way into the chamber, and a door with nothing to seal against.

The changes keep what the rig does: the same 36 L chamber, jacket, Peltier assembly, inner fin block, mixing fan, six bays, references, bubbler, dryer, HEPA loop, aerosol port, controller, supply and salt jars, in the same places. Nothing here changes the pitch or the safety case. Every change is in `cad/src/model.py`, which now builds each component separately and runs 79 constructability checks (`python cad/src/model.py --check`): parts that must touch do touch, and parts that must stay apart are apart by at least the stated clearance. All 79 pass.

## Options considered

For each problem the simplest change that a maker with a laser cutter, a saw, a drill and a 3D printer can build was chosen, keeping every part in its concept position where possible. The alternatives weighed are given in the "Why this way" column.

## Decision

*Table 1. Changes made to the model, the BOM and the calculations.*

| # | Problem in the concept | Change made | Why this way |
| --- | --- | --- | --- |
| P1 | The door was a 412 x 312 mm sheet the size of the shell, sealing on the 6 mm front edges of the walls, too narrow for a D-section gasket. Its two latches were blocks on the door with nothing to catch on. | A 6 mm acrylic front frame, 450 x 350 mm with a 400 x 300 mm window, is solvent-welded to the shell's front edges and covers 19 mm of the jacket's front edges. The gasket sits on the frame 4 to 12 mm outside the opening. The door is 430 x 330 mm and overlaps the opening by 15 mm. Four draw latches (not two) sit on four 41 x 40 mm tabs on the frame, and hook keepers on the door. | Gives the gasket a 25 mm wide face and the latches something to pull against. Four latches squeeze a 430 mm long gasket evenly; two at mid-height would leave the corners loose. The frame is cut from the same sheet as the shell. |
| P2 | The removable door panel (462 x 362 mm) stood in front of the latches with no fixing. | The panel is 406 x 330 mm, covers the opening with 3 mm to spare each side, sits flat on the door between the latches and is held by four hook-and-loop pads. | No new hardware; it comes off by hand for the warm, dry points. The door's inside area that the condensation check uses (400 x 300 mm) is still covered. |
| P3 | The Peltier assembly passed through the wall with nothing clamping it to the wall, and its block floated in the opening. | The inner and outer sink bases (120 x 110 mm) clamp the right wall between them with four M4 stainless screws at 57 mm either side and 42 mm above and below the centre. The screws pass through rigid sleeves in the jacket so the foam is not crushed. The 80 x 80 mm module and spacer block sits in the 90 x 100 mm opening with 5 mm all round, filled with XPS offcuts and sealant. | This is how air-to-air thermoelectric assemblies are normally mounted through an insulated wall. Sink sizes, the fin block and the thermal path are unchanged. |
| P4 | The mixing fan floated 5 mm off the back wall with no fixing. | Four 12 x 12 x 15 mm acrylic spacers are welded to the inside of the back wall; the fan screws to them with M4 nylon screws, 15 mm off the wall. | No hole through the wall, so no leak; 15 mm lets the fan draw air from behind. |
| P5 | The tray stood on four 5 x 5 mm posts, and its perforation was not defined. | Four 10 x 10 x 50 mm welded legs, 10 mm in from each corner; 87 holes of 8 mm on a 24 mm grid (none over the legs). The tray stands loose and lifts out through the door. | 5 mm posts are too thin to weld square. The hole grid gives the "perforated" tray of the concept. |
| P6 | The reference mast stood behind the tray at tray-top height with nothing under it. | A printed 20 x 20 mm mast stands on the chamber floor against the back of the tray rail, held by two M4 nylon screws; the reference carrier screws onto its top. The references stay 120 mm above the tray. | Nothing is screwed into the shell, and the mast comes out with the tray. |
| P7 | The bubbler and dryer lines stopped at the jacket face with no fitting through the wall; the dryer line ended 10 mm short of the column; and the loop had no way out of the chamber, so the two pumps (in BOM lines 9 and 10, not modelled) had nothing to draw from. | Three 12 mm barbed bulkhead fittings in the right wall: the wet inlet, the dry inlet and a new suction port 20 mm above the floor. Two air pumps on the base draw through the suction port. The dryer line turns into the column. The dryer stands in a printed socket screwed to the base; the bubbler moved 10 mm back to clear the front frame. | A closed loop needs an outlet as well as inlets, as the precis describes ("draw air from the chamber and return it"). Bulkheads seal on the acrylic; the jacket holes are 4 mm clear. |
| P8 | The HEPA unit stood behind the chamber with no connection to it. | Two 12 mm bulkhead fittings in the back wall, 80 mm apart and 77 mm above the floor, run straight into the HEPA unit's ports. | The shortest air path; the unit pushes onto the fittings and is then screwed down. |
| P9 | The sensor and reference leads passed through one gland in the door, with no position given; opening the door would drag every lead. | Two M20 cable glands with multi-hole seal inserts in the back wall, 37 mm above the floor; the USB and I2C hub moves to the controller behind the chamber. | Leads stay put when the door opens; the gland is no longer in the clear door. |
| P10 | The precis keeps a drip tray and drain for cold points, but the model had none. | A 50 x 130 x 14 mm acrylic drip tray welded to the right wall 4 mm under the inner sink; a 6 mm drain bulkhead just above its floor; a line to a 250 mL bottle on the base. | Water from the inner sink at cold points leaves the chamber instead of pooling on the floor. |
| P11 | The aerosol port's 16 mm stub floated in a 20 mm hole. | The shell hole is 16 mm, the stub is a bulkhead with a nut inside, and the jacket hole is 32 mm. | Seals on the acrylic like the other bulkheads. |
| P12 | The salt jars stood loose on the base. | A printed rack with four pockets, screwed to the base. | Keeps the jars upright and labelled. |

*Table 2. Knock-on changes.*

| Item | Change | Reason |
| --- | --- | --- |
| Base plate | 9 mm sealed birch plywood instead of 12 mm (plywood or HDPE), six rubber feet. Overall height 371 mm (was 374 mm). | The added acrylic, fittings and holders added about 0.7 kg; the thinner base saves 0.5 kg, so the rig is 13.83 kg against R13's 14 kg [A3]. The chamber and jacket stiffen the base where it carries load. |
| Mass | 13.8 kg (was 13.6 kg), R13 still met with 0.17 kg margin. | CLR-CAL-001 v0.4 [A3]. |
| Cost | $439 on 19 lines (was $412 on 18): lines 1, 2, 3, 5, 10 and 15 repriced and line 19 (bulkhead fittings, cable glands and drain, $14) added. R12 is now over the value-engineering target by $27; see A1. | Parts added for construction. `budget_usd` is unchanged at $412. |
| Wiring | The two bimetal cut-offs hold in a relay on the Peltier and heater supply (BOM line 13, no price change). | Small bimetal switches are often not rated to break about 5 A of direct current; a relay keeps the cut-off independent of the software, as R16 requires. |
| Thermal | Heat capacity 8.7 kJ/K (was 8.6); 40 to 20 °C in 78 min (was 77); 10 °C reached in 2.5 h (was 2.4 h). Every other result is unchanged. | The heat balance uses the inside areas, which did not change [B7, B8]. |
| Drawings | CLR-DWG-001 Rev P4; making sketches CLR-DWG-101 to 111 added. | Follow the model. |
| Documents | CLR-CAL-001 v0.4, CLR-REQ-001 v0.6, CLR-PRC-001 v0.6; build plan CLR-BLD-001 and register CLR-DEC-001 added. | Follow the model. |

*Table 3. Proposed; A2 and A3 accepted by Amish as recommended on 2026-10-02.*

| # | Question | Options | Recommendation |
| --- | --- | --- | --- |
| A1 | The parts that make the design buildable bring the estimated cost to $439, $27 over the $412 value-engineering target (a hypothetical control target, not a limit). | Savings worth trying: (a) a core version without CO2 (about $372), which drops the SCD30 and soda lime and so changes what the rig does; (b) look for $27 of savings elsewhere, which no line obviously offers; (c) re-price at purchase. | No change to the target; keep the design and re-price at purchase. |
| A2 | The R13 mass margin is now 0.17 kg, on estimated masses. | (a) accept, and weigh the prototype at TRL 4; (b) look for more mass now (for example 5 mm acrylic for the top). | (a), with the 5 mm acrylic top as the first fallback if the finished rig weighs over 14 kg. Accepted 2026-10-02. |
| A3 | Base material. The appearance model proposes a dark HDPE base (REVIEW 2026-09-26, item 2); a 12 mm HDPE base would weigh about 3.4 kg and take the rig to about 15.8 kg, over R13. | (a) sealed 9 mm birch plywood, as modelled; (b) HDPE, with R13 relaxed again; (c) 6 mm HDPE (about 1.7 kg) on more feet. | (a), and keep HDPE for the renders only if Amish prefers its look. Accepted 2026-10-02 as (a), with the renders drawn in plywood too so they match what will be built. |

## Consequences

- `design_state: constructable` in `project.yaml`. The build plan CLR-BLD-001 shows every component and step in pictures generated from the model (`cad/src/build_plan_media.py`).
- Requirement status (CLR-CAL-001 v0.4): met 12, at risk 3 (R4, R5, R6), not met 1 (R8), over the value-engineering target 1 (R12), not verifiable at TRL 3 1 (R14).
- The appearance model `cad/src/product_model.py` was brought in line with this design on 2026-10-02 (front frame, four latches, back-wall glands and bulkheads, drain, pumps, 9 mm plywood base) and its render scenes exported; the photoreal renders (`media/render-*.png`), `media/card.png` and `media/social-preview.png` are redrawn from them on Amish's Mac.
- With A2 and A3 accepted, the rig is weighed at TRL 4 (5 mm acrylic top as the first fallback over 14 kg) and the base stays 9 mm sealed birch plywood. After the front badge, door border and pull handle adopted on 2026-10-02 the estimated mass is 13.92 kg, a 0.08 kg margin (CLR-CAL-001 v0.7).
- Parts to check when they are bought (sink base size and clamp holes, latch footprint, bulkhead and gland sizes, HEPA port spacing) are listed in the design decisions register, CLR-DEC-001.

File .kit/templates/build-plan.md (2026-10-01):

---
doc_id: PRJ-BLD-001
title: Project prototype build plan
project: Project name
doc_type: Build plan
version: "0.1"
status: Draft
date: YYYY-MM-DD
author: Amish Chadha
license: CERN-OHL-S-2.0
revisions:
  - version: "0.1"
    date: YYYY-MM-DD
    author: Amish Chadha
    change: First build plan; design made constructable
---

# Project prototype build plan

**Plan, not yet built.** How to build the first proof-of-concept prototype, component by component. Building and testing to it is TRL 4 work. Decisions still to be made are kept in the design decisions register (`docs/06-design-decisions.md`), not here.

## 1. What you are building

Every component, pulled apart and numbered in build order

One short paragraph: what the prototype is, how many components, which are made and which are bought, and the main ways they are made.

## 2. What changed to make it buildable

| Component | The concept had | The buildable design has | Why |
| --- | --- | --- | --- |

## 3. Making the components

### 3.1 Component name

Making sketch

**What it is and what it is made from.**

**How to make it.**

1. Mark out ...
2. Cut ...

**How it fits the parts next to it.**

Close-up of the joint

**Check before moving on.**

## 4. Putting it together

### Step 1: ...

Step 1

## 5. First checks

| Check | Requirement | How | Pass when |
| --- | --- | --- | --- |

## 6. Safety stops

## 7. Tools, skills and workspace

## 8. Where the numbers come from

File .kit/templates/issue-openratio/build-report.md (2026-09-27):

---
name: Build report
about: Tell us what happened when you built, printed or tested part of this design
title: "Build report: "
labels: build-report
---

This is a research and educational prototype, not a medical device. It is a TRL 3 concept and is not released for fabrication. If you build any part of it, you do so at your own risk. Reports help everyone.

**What you built** (part, sub-assembly or test)

**Materials, tools and settings**

**What worked**

**What did not work, with photos or measurements if you have them**

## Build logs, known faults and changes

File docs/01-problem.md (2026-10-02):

---
doc_id: CLR-PRB-001
title: CalRig problem statement
project: CalRig
doc_type: Problem statement
version: "0.6"
status: Draft
date: '2026-10-02'
author: Amish Chadha
license: CERN-OHL-S-2.0
revisions:
- version: "0.1"
  date: '2026-09-25'
  author: Amish Chadha
  change: Initial scaffold
- version: "0.3"
  date: '2026-09-25'
  author: Amish Chadha
  change: Populate to TRL 2 (problem, users, context, constraints, out of scope, prior work with sources)
- version: "0.3"
  date: '2026-09-25'
  author: Amish Chadha
  change: Budget and gas scope lines updated for CLR-DDR-001 (A1, A5)
- version: "0.4"
  date: '2026-09-25'
  author: Amish Chadha
  change: Recommendations accepted by Amish (DDR-002)
- version: "0.5"
  date: '2026-09-26'
  author: Amish Chadha
  change: Budget approved by Amish; constraint now $412
- version: "0.6"
  date: '2026-10-02'
  author: Amish Chadha
  change: 'Open questions on collocation and report format answered by the decisions of 2026-10-02 (CLR-DEC-001)'
---

# CalRig problem statement

Low-cost sensors drift and disagree, and without calibration their data is not trusted by cities, regulators or researchers. Community groups, schools and small labs can buy a particle, humidity or CO2 sensor for tens of dollars, but they have no affordable way to check it against a known value before deployment, after a season in the field or after a repair. CalRig is a bench-top chamber that sets known temperature, humidity and particle conditions around a batch of sensors and compares them with reference instruments, so each sensor leaves with a dated calibration record.

## The problem

Low-cost sensors are now the main source of local air and climate data in many places, but their raw readings are biased in ways that depend on the environment:

- **Humidity bias in particle sensors.** Optical particle sensors count water-swollen particles as dry mass. A US-wide study of 53 PurpleAir sensors at 39 sites found that raw readings overestimated PM2.5 by about 40 % in most of the country, and that a correction with a humidity term cut the root mean square error from 8 to 3 µg/m³ ([Barkjohn et al., 2021](https://amt.copernicus.org/articles/14/4617/2021/)).
- **Temperature and humidity dependence of gas sensors.** Electrochemical and metal-oxide gas sensors respond to temperature and humidity as well as to the target gas, which is why the European sensor evaluation specification tests sensor systems across both ([CEN/TS 17660-1:2021](https://standards.iteh.ai/catalog/standards/cen/5bdb236e-95a3-4b5b-ba7f-62ab08cd21f8/cen-ts-17660-1-2021)).
- **Drift over time.** The UK Air Quality Expert Group warns that "without any ongoing quality control and calibration of these devices in the field their lifespan for producing useful data will always be limited" ([DEFRA AQEG](https://uk-air.defra.gov.uk/research/aqeg/pollution-sensors/how-could-I-use.php)).

The recognized fixes are collocation beside a regulatory monitor for weeks, and chamber tests at set temperature and humidity. The US EPA's performance targets for PM2.5 sensors ask for at least 30 days of field collocation with at least three identical sensors, plus enhanced lab tests at 20 °C and 40 °C and at 40 % and 85 % RH ([EPA FAQ on sensor testing reports](https://www.epa.gov/air-sensor-toolbox/frequently-asked-questions-reports-air-sensor-performance-testing-protocols)). Programs with a full chamber, such as South Coast AQMD's [AQ-SPEC](https://www.aqmd.gov/aq-spec), are few and expensive. Where regulatory monitors are absent, collocation is not possible at all: in 2020, OpenAQ found evidence that only 49 % of national governments produced any air quality data ([OpenAQ, 2020](https://documents.openaq.org/reports/Open+Air+Quality+Data+Global+State+of+Play+2020.pdf)).

A small group therefore either trusts factory calibration, which the studies above show is not enough, or does nothing. CalRig aims to make the chamber half of the process cheap, open and repeatable, and to make collocation more efficient by carrying a collocated "transfer" sensor back to the bench.

## Users and context

| User | Need | Context |
| --- | --- | --- |
| Lab and project builders (Design Molecule projects such as AirStreet, HeatMap Node and DustBadge) | Check every sensor before and after deployment and after repairs | Bench space, 12 V supply, batches of 1 to 6 sensor heads |
| Community air quality groups | Show that their network data is credible to a city or a newspaper | Volunteer-run, small budgets, sensors from mixed makers |
| Universities and schools in low-monitoring countries | Characterize sensors locally where no regulatory monitor exists nearby | Teaching labs, local suppliers, hot and humid climates |
| Municipal environment teams | Screen low-cost sensors before a procurement or a pilot | Small technical staff, need a documented method |
| Building and HVAC technicians | Check CO2 and humidity sensors used for ventilation control | Service vans and workshops |

### Operating environment

- **Room:** indoor lab or workshop at 15 to 30 °C, 20 to 80 % RH, on a bench about 0.9 m high.
- **Power:** a certified external 12 V supply from a normal socket; no mains wiring inside the rig.
- **Consumables:** distilled water, indicating silica gel, analytical-grade salts for fixed points, incense or a candle for test aerosol, soda lime for CO2 zero.
- **Operator:** one person with basic electronics skills; runs are unattended once started.

## Constraints

- Garage-buildable prototype, $412 USD in parts (`budget_usd`, raised from $300 to $400 by Amish on 2026-09-25 and to $412 on 2026-09-26, CLR-DDR-002). CLR-CAL-001 v0.3 prices the design at about $412 (REQ-001 R12, met).
- Built from sheet acrylic, off-the-shelf thermoelectric, pump and sensor modules, and a small microcontroller; no machining beyond cutting and drilling.
- Uses only low-hazard test atmospheres: water vapor, room air, combustion smoke in small amounts, exhaled CO2. No toxic calibration gases in the first version.
- Open data: every run writes plain CSV and a readable report; software under MIT.
- Results must be described plainly: CalRig gives a characterized, documented comparison against transfer references. It does not by itself make a sensor a regulatory or equivalent method.

## Out of scope

- Regulatory certification or equivalence testing of sensors.
- Toxic reference gases (NO2, O3, CO, SO2) and gas dilution systems. NO2 sensors are calibrated by field collocation only (CLR-DDR-001 A5, decided by Amish on 2026-09-25).
- Noise, light, wind and water quality sensors.
- Particle size-resolved reference measurement; CalRig checks mass concentration against a collocated transfer sensor only.
- Field collocation hardware; CalRig relies on existing regulatory or research sites for that step.

## Prior work

- **AQ-SPEC** (South Coast AQMD) runs field and chamber evaluations of commercial sensors and publishes its [laboratory protocol](https://www.aqmd.gov/docs/default-source/aq-spec/protocols/sensors-lab-testing-protocol6087afefc2b66f27bf6fff00004a91a9.pdf). It sets the method CalRig follows in a much simpler form.
- **US EPA performance targets** for PM2.5 sensors set R² ≥ 0.70, slope 1.0 ± 0.35, intercept within ±5 µg/m³, RMSE ≤ 7 µg/m³ and precision SD ≤ 5 µg/m³ ([EPA/600/R-20/280](https://cfpub.epa.gov/si/si_public_record_report.cfm?Lab=CEMM&dirEntryID=350785), values as listed in the [EPA sensor loan program QAPP](https://www.epa.gov/system/files/documents/2024-06/particulate-matter-pm2.5-sensor-loan-program-qapp-aasb-qapp-004-r1.1.pdf)). CalRig reports its results against these metrics.
- **Saturated salt fixed points.** Greenspan's tables give equilibrium relative humidity over saturated salt solutions, for example 75.29 ± 0.12 % RH for sodium chloride at 25 °C ([Greenspan, 1977](https://nvlpubs.nist.gov/nistpubs/jres/81A/jresv81An1p89_A1b.pdf)). These are the cheapest traceable humidity references available.
- **Local calibration in Africa.** AirQo and university partners in Uganda calibrate low-cost PM2.5 sensors against reference instruments for urban and rural sites ([Calibration of low-cost sensor data in South Central Uganda](https://www.sciencedirect.com/science/article/pii/S1309104225001825); [World Economic Forum on AirQo](https://www.weforum.org/stories/2022/06/ugandan-researchers-low-cost-sensors-air-pollution/)). This shows the demand for local calibration capacity.
- **Commercial humidity generators and environmental chambers** exist but cost thousands of dollars and are not open.

## Open questions

- Which sensors do the first users most need to check: PM2.5, temperature and humidity, CO2, or NO2?
- Is there a regulatory or research monitor within reach of the first users for collocating the transfer PM sensor? (Decided 2026-10-02: a state or local regulatory site with a federal equivalent PM2.5 monitor; first candidate to approach a Texas Commission on Environmental Quality site in Dallas-Fort Worth.)
- What report format would a city or a funder accept as evidence of sensor quality? (Decided 2026-10-02: one based on the US EPA 2021 performance targets and testing protocol for PM2.5 air sensors, with a stated uncertainty chain.)

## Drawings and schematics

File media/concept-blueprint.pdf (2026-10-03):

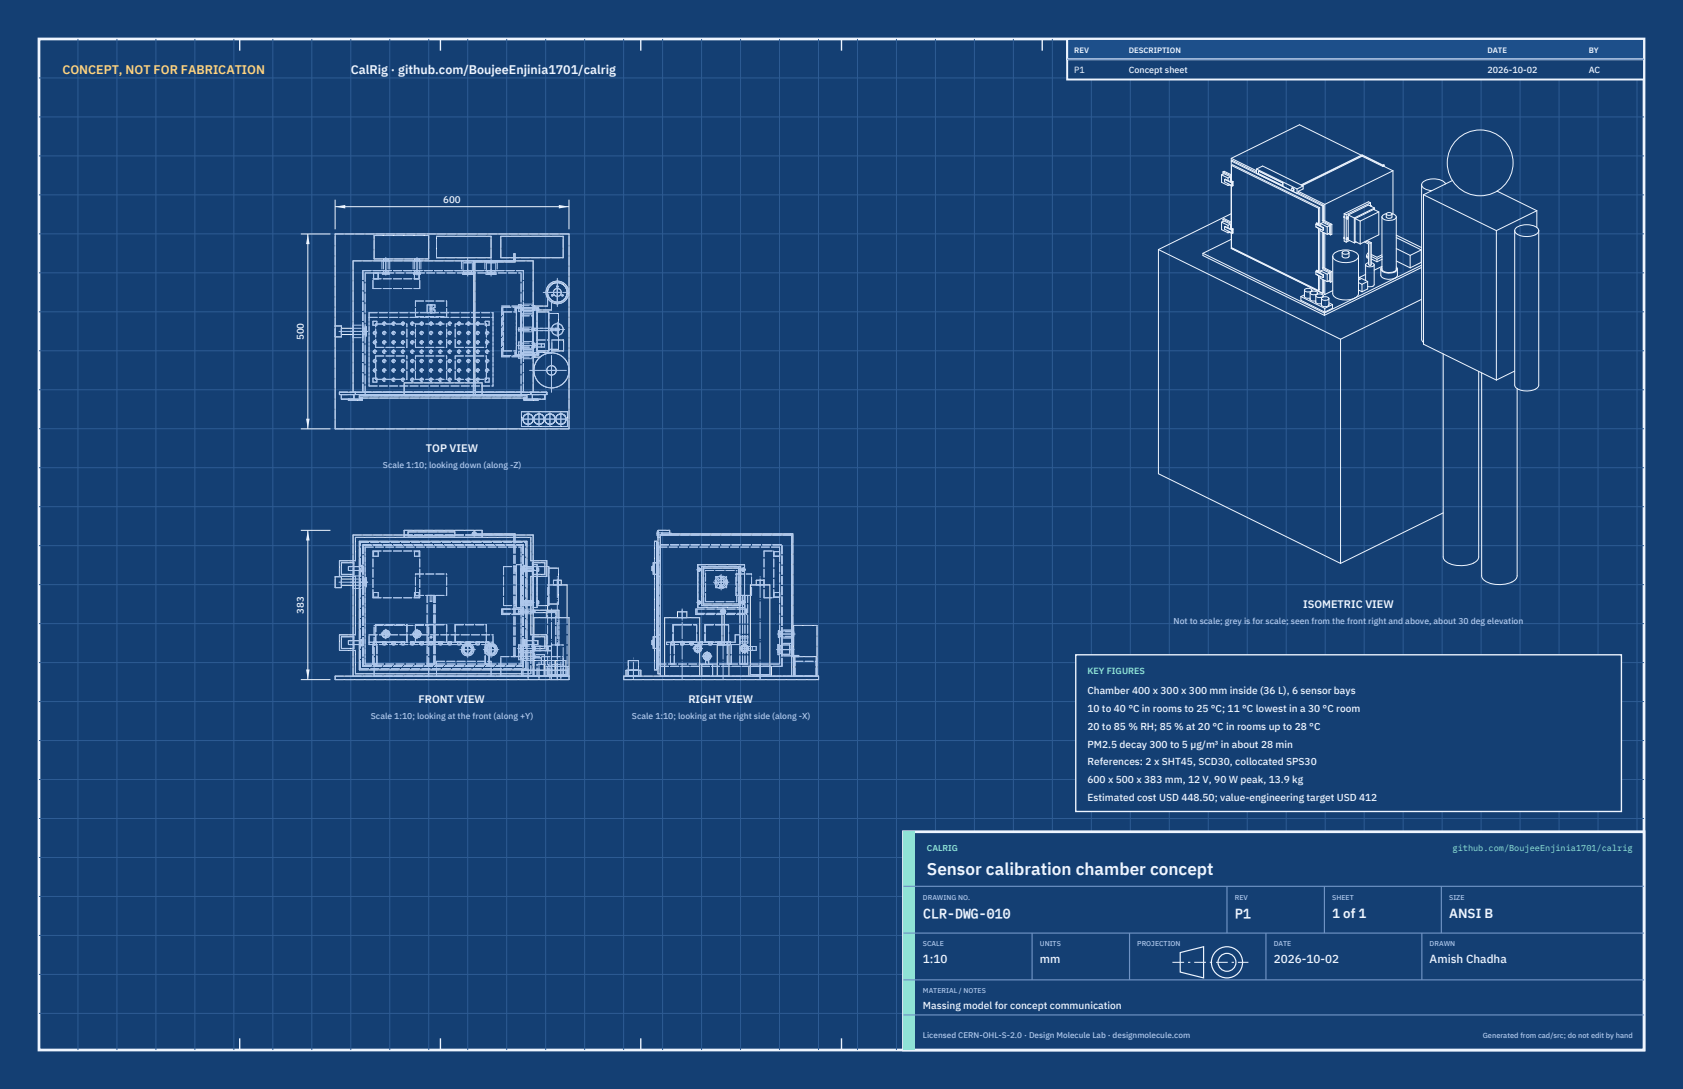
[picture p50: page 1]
CONCEPT, NOT FOR FABRICATION; CalRig · github.com/BoujeeEnjinia1701/calrig; FRONT VIEW; TOP VIEW; RIGHT VIEW; ISOMETRIC VIEW; REV; DESCRIPTION; DATE; Concept sheet; CALRIG; github.com/BoujeeEnjinia1701/calrig; DRAWING NO. CLR-DWG-010; REV P1; SHEET 1 of 1; SIZE ANSI B; SCALE 1:10; UNITS mm; PROJECTION; DRAWN Amish Chadha; Licensed CERN-OHL-S-2.0 · Design Molecule Lab · designmolecule.com; Generated from cad/src; do not edit by hand

Scale 1:10; looking down (along -Z)

Not to scale; grey is for scale; seen from the front right and above, about 30 deg elevation

KEY FIGURES
Chamber 400 x 300 x 300 mm inside (36 L), 6 sensor bays
10 to 40 °C in rooms to 25 °C; 11 °C lowest in a 30 °C room
20 to 85 % RH; 85 % at 20 °C in rooms up to 28 °C
PM2.5 decay 300 to 5 µg/m³ in about 28 min
References: 2 x SHT45, SCD30, collocated SPS30
600 x 500 x 383 mm, 12 V, 90 W peak, 13.9 kg
Estimated cost USD 448.50; value-engineering target USD 412

Scale 1:10; looking at the front (along +Y)

Scale 1:10; looking at the right side (along -X)

Sensor calibration chamber concept

MATERIAL / NOTES
Massing model for concept communication

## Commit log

2026-09-25 Initial scaffold: standard open hardware layout, CERN-OHL-S v2 + MIT licenses
    Claude-Session: https://claude.ai/code/session_01XuhhSU4W6fYhgCfURbrkut
    [bom.csv]
2026-09-25 Populate to TRL 2: problem, requirements, precis, concept media, BOM and README use cases
    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
    [bom.csv]
2026-09-26 Advance to TRL 3: DDR-001, CAL-001 sizing, parametric model with STEP/STL, GA drawing, priced BOM; TRL 4 on hold
    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
    [bom.csv, calrig-assembly.step, calrig-assembly.stl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]
2026-09-26 Accept all recommendations (DDR-002), switch footer to designmolecule.com, add README write-up with new inspiration point
    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
    [bom.csv, calrig-assembly.step, calrig-assembly.stl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]
2026-09-27 Product appearance model and photoreal renders
    Adds cad/src/product_model.py (appearance model for renders only, all main
    dimensions from model.py) and Blender renders in media/render-*.png,
    captioned with the project, repository and viewing direction. README leads
    with the product render; trl stays 3.
    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
2026-10-01 Image quality pass: legible exploded views, flow diagrams and drawing sheets
    Kit 1.6.1 image layout: the parts list sits in its own column, number bubbles sit on visible parts and never overlap, small parts get a leader, pictures are cropped to the subject, flow labels keep numbers with their units, and sheet captions and the revision table no longer overprint. Concept images, blueprint and general arrangement sheet regenerated; repo-specific labels moved clear of other text and lines.
2026-10-01 Kit 1.7.0: constructable design, illustrated build plan and design decisions register
    The design is now constructable: every part can be made and fits its neighbours, with each change recorded in a Design for construction decision record (made under Amish's 2026-09-30 instruction; ope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
    [bom.csv, calrig-assembly.step, calrig-assembly.stl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]
2026-10-01 Budget treated as a value-engineering target
    Amish, 2026-10-01: the budget is a hypothetical control target that keeps the design on a value-engineering lens, not a spending limit. Documents now state the value-engineering target and the estima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
2026-10-02 Record Amish's approval of the open-decision recommendations
    Amish approved the recommendation on every open decision in the design decisions register ("i approve your recommendations for all 555 open decisions.", 2026-10-02). Each decision is moved to Decisio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
2026-10-03 Carry approved follow-ups into the design and redo photoreal renders
    Amish approved the follow-up actions from the open-decision sign-off ("APPROVED CHANGES, COMPLETE THESE", 2026-10-02), the design-for-construction change tables in ten repos, the last wave's open dec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
    [bom.csv, calrig-assembly.step, calrig-assembly.stl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]

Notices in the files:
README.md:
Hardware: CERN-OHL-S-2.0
